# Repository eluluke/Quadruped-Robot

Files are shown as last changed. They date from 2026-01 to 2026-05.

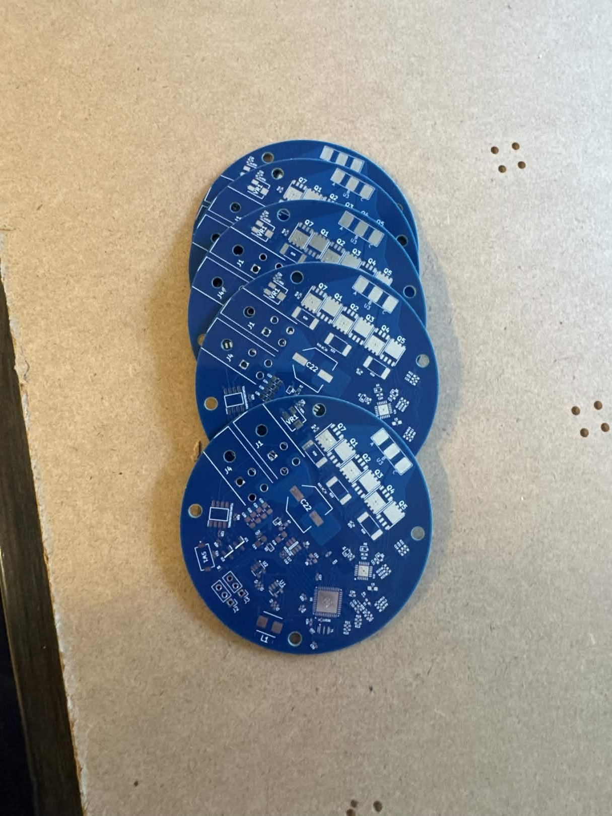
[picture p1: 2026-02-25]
Documentation/IMG_2081.jpg

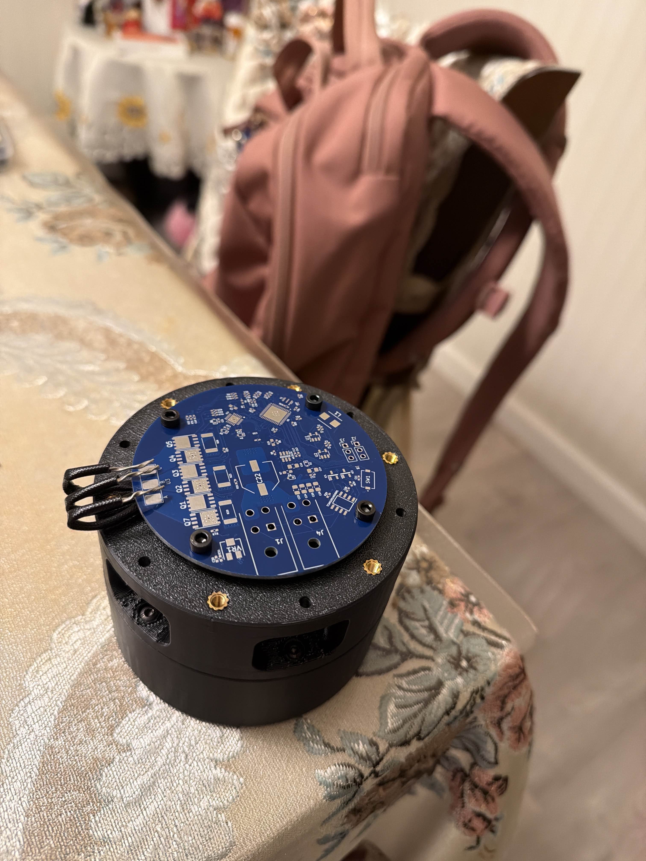
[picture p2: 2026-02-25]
Documentation/IMG_6219.jpg

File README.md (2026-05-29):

# Quadruped Robot

Open-source, 3D-printable, modular quadruped robot designed as a hardware platform for robotics education, controls development, kinematics, reinforcement learning, robotic vision, and future semi-commercial research applications.

This project focuses on building a practical legged robot platform using custom cycloidal actuators, off-the-shelf electronics, CAN-based motor communication, and open-source low-level motor control software. The goal is to create a robot that is mechanically capable, reproducible, and flexible enough for future work in locomotion, autonomous navigation, and robotics research.

## Project Overview

The quadruped is a 12-degree-of-freedom robotic platform with three actuated joints per leg. The mechanical design uses custom 3D-printed cycloidal actuators with a 17:1 gear ratio. These actuators were designed to make the robot modular, serviceable, and easier to manufacture using accessible tools such as 3D printers.

The CAD design is complete, and the actuator assemblies have been built. The current electronics setup uses off-the-shelf hardware for development and testing, while the repository also includes ongoing custom FOC driver board design files. Software development is focused on low-level actuator communication, calibration, inverse kinematics, single-leg testing, and full quadruped locomotion.

Full walking is still under development.

## Current Status

| Area | Status |
| --- | --- |
| CAD design | Complete |
| Actuator design | Complete |
| Actuator build | Complete |
| Electronics | Off-the-shelf electronics currently used for development |
| Custom FOC board | KiCad design files included / in development |
| Low-level motor communication | Based on Berkeley Humanoid Lite low-level code |
| Calibration scripts | In progress |
| Single-leg control | In progress |
| Full quadruped walking | In development |
| Vision/autonomy | Future work |

## Features

* 12-DOF quadruped layout
* Three actuators per leg
* Custom 17:1 cycloidal actuator design
* 3D-printable mechanical structure
* Modular leg and actuator design
* CAD files for the full robot body, legs, and accessories
* CAN-based actuator communication
* Low-level motor control using Berkeley Humanoid Lite/Recoil-style communication code
* Calibration scripts for actuator setup and configuration
* Forward and inverse kinematics tools
* Early locomotion and gait-control scripts
* Xbox controller testing scripts for manual actuator/robot control
* KiCad files for custom FOC driver board development
* BOM and purchasing documentation

## Repository Structure

```text
Quadruped-Robot/
├── 3D_Model/
│   ├── Accessory/
│   ├── Quadruped Body/
│   └── Quadruped Leg/
│
├── Control_Code/
│   ├── Calibration/
│   ├── Locomotion/
│   ├── lowlevel_actuator/
│   ├── quad_ik_can/
│   └── recoil/
│
├── Documentation/
│
├── KiCAD Files/
│   ├── 3D models/
│   ├── BHL_S1_Current/
│   ├── Footprints/
│   ├── Protoype1_Final_revision/
│   └── Symbols/
│
├── Motor_Firmware/
│
├── Purchasing/
│   ├── BOM/
│   └── RFF/
│
└── README.md
```

## Folder Descriptions

### `3D_Model/`

Contains the mechanical design files for the robot. This includes accessory parts, the quadruped body assembly, and leg assembly files.

Important areas include:

* `Accessory/` — printable accessory parts such as body covers and handles
* `Quadruped Body/` — full robot body assembly files
* `Quadruped Leg/` — leg assembly files

These files are used for manufacturing, assembly planning, and future mechanical revisions.

### `Control_Code/`

Contains the Python control software for actuator testing, calibration, kinematics, and early locomotion development.

#### `Control_Code/Calibration/`

Scripts used for setting up and validating individual actuators and motor controllers.

Examples include:

* `ping.py` — basic communication test
* `calibrate_electrical_offset.py` — motor/encoder electrical offset calibration
* `configure_parameter.py` — motor controller parameter configuration
* `read_configurations.py` — read back motor controller settings
* `move_actuator.py` — basic actuator motion test

#### `Control_Code/Locomotion/`

Main area for robot-level locomotion development.

Includes:

* Forward kinematics
* Inverse kinematics
* Leg configuration
* Gain configuration
* Gait scheduling
* Robot controller scripts
* Xbox controller configuration
* IMU reading utilities
* Single-leg and quadruped testing scripts

Notable files include:

* `quadruped_leg_fk.py`
* `quadruped_leg_ik.py`
* `leg_controller.py`
* `robot_controller.py`
* `gait_scheduler.py`
* `quadruped_main_slim.py`
* `quadruped_main_state.py`
* `single_leg_trot.py`
* `remote_single_leg_trot.py`
* `xbox_home_v5.py`
* `read_bno055_live.py`

#### `Control_Code/lowlevel_actuator/`

Contains lower-level actuator test scripts used to command one or more actuators directly.

Examples include:

* `actuator_move_position.py`
* `actuator_ramp_position.py`
* `actuator_ramp_rel_pos.py`
* `triple_actuator_homing.py`
* `triple_actuator_rel_pos.py`
* `xbox_position_control_test.py`
* `xbox_velocity_control_test.py`

These scripts are useful for validating actuator behavior before integrating the full robot.

#### `Control_Code/quad_ik_can/`

Contains an additional inverse-kinematics-over-CAN control workflow.

Includes:

* `can_interface.py`
* `config.py`
* `ik_solver.py`
* `main.py`
* `README.md`

This section appears to be focused on combining inverse kinematics commands with CAN communication.

#### `Control_Code/recoil/`

Contains the low-level Recoil-style communication code used to interface with the FOC motor drivers.

This project uses the Berkeley Humanoid Lite low-level code as the foundation for communicating with the FOC drivers.

Files include:

* `can.py`
* `core.py`
* `fixed16.py`
* `util.py`

## Mechanical Design

The robot is built around custom cycloidal actuators. Each actuator is designed to be compact, modular, and manufacturable with accessible tools. The use of a cycloidal gearbox provides a high reduction ratio while keeping the actuator package suitable for legged robotics.

The mechanical system was designed with the following goals:

* Keep the robot modular and easy to repair
* Make the actuator design reproducible
* Use 3D printing where practical
* Reduce complexity compared to fully custom machined systems
* Provide enough torque and structure for walking development
* Create a platform that can support future controls and autonomy work

## Electronics

The current robot uses off-the-shelf electronics for development and testing. This makes it easier to focus on actuator validation, CAN communication, calibration, and walking control before depending on fully custom hardware.

The repository also includes KiCad files for custom FOC driver board development. These files include PCB designs, schematics, footprints, symbols, 3D models, and previous design revisions.

### `KiCAD Files/`

This folder contains custom motor controller PCB design files and related KiCad resources.

Included resources:

* KiCad project files
* PCB layout files
* Schematic files
* Footprints
* Symbols
* 3D models
* Older board revisions
* Prototype revisions

This section is useful for future development of custom motor-control electronics.

### `Motor_Firmware/`

Contains motor firmware resources, including a modified Recoil motor controller firmware archive.

## Software

The control software is written primarily in Python and is organized around actuator bring-up, calibration, inverse kinematics, and locomotion development.

The current low-level communication approach is based on the Berkeley Humanoid Lite low-level code. This code is used to communicate with the FOC drivers and send actuator commands over CAN.

### Software Goals

* Establish reliable communication with each actuator
* Test individual motor and actuator behavior
* Validate actuator direction, encoder feedback, and control modes
* Calibrate electrical offsets and controller parameters
* Develop single-leg control
* Develop inverse kinematics for each leg
* Build toward coordinated full-body locomotion
* Eventually support higher-level walking, autonomy, and vision experiments

## Running and Testing

Example test scripts are available in the Berkeley Humanoid Lite low-level software and in this repository’s `Control_Code/` folder.

A typical development workflow is:

1. Set up the Python environment.
2. Connect the CAN interface and motor controller hardware.
3. Confirm communication with the actuator.
4. Run a basic ping or configuration read test.
5. Calibrate the actuator electrical offset.
6. Test basic actuator movement.
7. Test multiple actuators together.
8. Run inverse kinematics tests.
9. Test single-leg motion.
10. Move toward full quadruped locomotion.

Example scripts to start with:

```bash
python Control_Code/Calibration/ping.py
python Control_Code/Calibration/read_configurations.py
python Control_Code/Calibration/calibrate_electrical_offset.py
python Control_Code/Calibration/move_actuator.py
```

For low-level actuator tests:

```bash
python Control_Code/lowlevel_actuator/actuator_move_position.py
python Control_Code/lowlevel_actuator/actuator_ramp_position.py
python Control_Code/lowlevel_actuator/triple_actuator_homing.py
```

For locomotion and kinematics development:

```bash
python Control_Code/Locomotion/ik_terminal_test.py
python Control_Code/Locomotion/single_leg_trot.py
python Control_Code/Locomotion/quadruped_main_slim.py
python Control_Code/Locomotion/quadruped_main_state.py
```

Exact commands may need to be adjusted depending on the CAN interface, operating system, motor IDs, and hardware configuration.

## Development Notes

This project is still actively being developed. Many scripts are experimental and may need to be updated for a specific hardware setup.

Before running full robot tests, verify:

* CAN interface name and bitrate
* Motor controller IDs
* Encoder direction
* Motor phase order
* Joint limits
* Homing offsets
* Control gains
* Power supply current limit
* Emergency stop or disconnect method

## Safety Notes

This project involves motors, gear reductions, motor controllers, power electronics, and moving robotic limbs. Use caution when testing.

Recommended safety practices:

* Test actuators one at a time before full robot integration
* Keep the robot lifted or supported during early walking tests
* Use current limits during initial motor testing
* Keep hands, wires, and tools away from moving joints
* Have an emergency stop or quick power disconnect available
* Double-check wiring before applying power
* Verify motor direction before installing actuators into the full robot
* Confirm joint limits before running autonomous motion
* Avoid testing high-power motion near people or fragile objects
* Monitor motor and driver temperature during testing
* Do not leave powered actuators unattended

This robot is still under development, so all testing should be done carefully and incrementally.

## Documentation

The `Documentation/` folder contains project images and supporting documents. More build documentation, assembly instructions, wiring diagrams, CAD renders, and videos will be added as the project progresses.

## Purchasing and BOM

The `Purchasing/` folder contains bill of materials files, expense tracking, and request-for-funding documentation.

This includes:

* FOC drive board BOM
* Overall robot BOM
* Expense tracker
* Funding/request documentation

These files are useful for tracking cost, sourcing parts, and documenting project funding.

## Roadmap

### Completed

* Designed the full quadruped CAD model
* Designed custom cycloidal actuators
* Built the actuator assemblies
* Created 3D-printable body, leg, and accessory files
* Set up off-the-shelf electronics for development
* Added low-level actuator testing scripts
* Added calibration scripts
* Added forward and inverse kinematics code
* Added early locomotion and single-leg test scripts
* Added KiCad files for custom FOC driver board development

### In Progress

* Low-level actuator testing
* Motor communication and control validation
* Actuator calibration
* Leg-level control development
* Gait scheduling
* Single-leg trot testing
* Full quadruped walking development

### Future Work

* Full quadruped walking demo
* Improved gait generation
* Higher-level body control
* Autonomous navigation
* Robotic vision integration
* Custom electronics refinement
* Cleaner software setup instructions
* Assembly guide
* Wiring diagrams
* CAD renders and demo videos
* More complete documentation for calibration and testing

## Acknowledgments

This project uses the Berkeley Humanoid Lite low-level code as the foundation for communication with the FOC drivers.

The project is inspired by open-source robotics platforms and the goal of making advanced legged robotics more accessible for students, researchers, and builders.

## Project Status Disclaimer

This repository is still a work in progress. The CAD and actuator builds are complete, but full walking control is still under development. Some scripts are experimental and may require hardware-specific configuration before use.

## License

License information has not been finalized yet. Add the appropriate license before using this project for public distribution or commercial work.

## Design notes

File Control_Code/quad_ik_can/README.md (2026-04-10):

# Quad Leg IK — CAN Tester
**STM32 BESC · CANable · SocketCAN · Python 3**

Interactive inverse kinematics visualiser that sends computed joint angles
over CAN bus to three STM32 BESC motor controllers — one per joint.

---

## Quick Start

### 1. Install dependencies

```bash
pip3 install python-can
# tkinter is usually built-in; if not:
sudo apt-get install python3-tk
```

### 2. Bring up the CANable

Plug in your CANable USB adapter, then:

```bash
sudo bash scripts/setup_can.sh          # default: /dev/ttyACM0
# or if your device is on a different port:
sudo bash scripts/setup_can.sh /dev/ttyACM1
```

This creates the `can0` SocketCAN interface at 1 Mbit/s.

### 3. Run the app

```bash
python3 main.py
```

---

## Files

```
quad_ik_can/
├── config.py          ← ALL tunable parameters (edit this first)
├── ik_solver.py       ← Pure IK math (no hardware dependency)
├── can_interface.py   ← python-can wrapper for STM32 BESC
├── main.py            ← tkinter GUI application
└── scripts/
    └── setup_can.sh   ← CANable bringup script
```

---

## Configuration  (`config.py`)

### Link Lengths
```python
L1 = 100.0   # mm — upper arm (hip → knee)
L2 =  90.0   # mm — lower arm (knee → ankle)
L3 =  70.0   # mm — foot link (ankle → toe)
```
Edit these (or use the GUI panel) once you have your measurements.

### CAN IDs
```python
CAN_ID_HIP   = 0x01
CAN_ID_KNEE  = 0x02
CAN_ID_ANKLE = 0x03
```
Also editable live in the GUI without restarting.

### Joint Limits
```python
HIP_LIMIT_DEG   = (-90.0,  90.0)
KNEE_LIMIT_DEG  = (  0.0, 150.0)
ANKLE_LIMIT_DEG = (-90.0,  90.0)
```
Angles outside these ranges are clamped before transmission and shown
in red in the GUI.

### Angle Offsets
```python
HIP_OFFSET_DEG   = 0.0
KNEE_OFFSET_DEG  = 0.0
ANKLE_OFFSET_DEG = 0.0
```
Added to each IK angle before sending. Use to zero mechanical offsets.

---

## CAN Frame Format (STM32 BESC)

| Field | Value |
|---|---|
| Arbitration ID  | Joint CAN ID (0x01 / 0x02 / 0x03) |
| DLC | 4 bytes |
| Data | IEEE-754 float32, little-endian, degrees |

Example — hip at 30.0°:
```
ID: 0x001   DLC: 4   Data: 00 00 F0 41
```

---

## Simulation Mode

If `python-can` is not installed **or** the CAN interface is not available,
the app runs in **SIMULATION MODE** — all IK math runs normally, angles
are displayed and logged, but no frames are sent. The CAN log shows
`[SIM]` and the status indicator turns orange.

---

## Parallelogram Linkage Note

The IK solver treats the leg as a standard 3-DOF serial chain. For a true
parallelogram linkage the actuated joint angle equals the effective link
angle (transmission ratio = 1.0). If your linkage has a different ratio set:

```python
KNEE_TRANSMISSION_RATIO = 1.0   # in config.py
```

The knee angle sent over CAN is multiplied by this value.

---

## Troubleshooting

| Symptom | Fix |
|---|-----|
| `can0: No such device` | Run `setup_can.sh` first |
| `Permission denied /dev/ttyACM0` | `sudo usermod -aG dialout $USER` then re-login |
| Motors don't move | Check CAN IDs match firmware; verify bitrate |
| Wrong angle direction | Flip sign with offset: `HIP_OFFSET_DEG = 0` + negate in `can_interface.py` |
| GUI doesn't open | `sudo apt-get install python3-tk` |

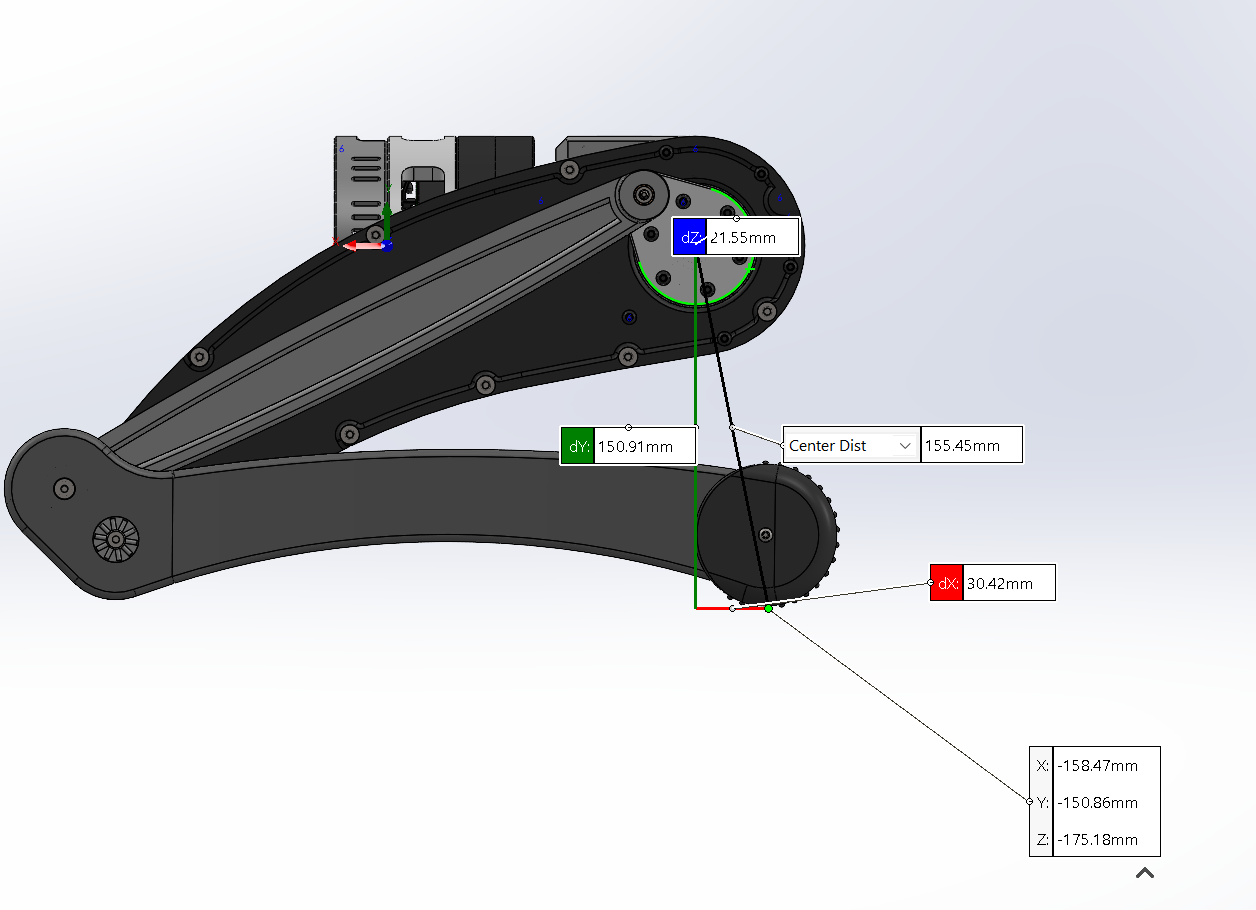
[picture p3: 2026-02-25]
Documentation/image.png

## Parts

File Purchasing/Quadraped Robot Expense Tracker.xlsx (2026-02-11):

Project
Expenses
Project | Start Date | End Date | Total: | $197.93
Quadraped Robot | 2025-11-15 | 2026-06-09
Member | Expense | Type | Amount | Notes
Elijah | DigiKey | Electrical | $8.76 | FOC Drive Board Components
Elijah | JLCPCB | PCB Board | $34.97 | FOC Drive Board
Elijah | Mouser | Electrical | $20.16 | FOC Drive Board Components
Elijah | DigiKey | Electrical | $126.04 | FOC Drive Board Components
Elijah | Amazon | Electrical | $8.00 | Molex connectors
MooMoo | Amazon | Gearbox |  | Cycloidal Gear Box Components
MooMoo | Amazon | Gearbox |  | Cycloidal Gear Box Components
MooMoo | Amazon | Gearbox |  | Cycloidal Gear Box Components
MooMoo | Amazon | Gearbox |  | Cycloidal Gear Box Components
Total |  |  | $197.93

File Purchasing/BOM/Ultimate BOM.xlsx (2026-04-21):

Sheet: Total Price
Item NO. | Item | Price | Quantity | Total | Item NO. | Item | Price | Total
1 | Actuator | $84.63 | 12 | $1015.58 | 1 | Actuator | $84.63 | $209.00 | In amazon cart
2 | Leg Assembly | $43.94 | 12 | $527.34 | 2 | Leg Assembly | $43.94 | $158.33 | In amazon cart
3 | FOC Drive Board | $38.51 | 12 | $462.17 | 3 | FOC Drive Board | $0.00 | $0.00
4 | Raspberry Pi 5 | $175.00 | 1 | $175.00 | 4 | Raspberry Pi 5 | $175.00 | $175.00 | https://www.canakit.com/raspberry-pi-5-8gb.html
5 | 3D Printer Filament | $15.00 | 4 | $60.00 | 5 | Motor Control Dev Board | $19.35 | $239.19 | https://www.digikey.com/short/43vvtr80
6 | Body Assembly | $89.98 | 1 | $89.98 | 6 | Body Assembly | $89.98 | $89.98 | In amazon cart
Total Project Cost: |  |  |  | $2330.07 | Additional Funding Needed: |  |  | $859.67
 |  |  |  |  |  | ^^^^^^^
 |  |  |  |  | This is the box that you should look at.

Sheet: Body Assembly
ITEM NO. | PART NUMBER | DESCRIPTION | Web Link for Purchasing | Cost per Time Purchased($) | Quantity Per Time Purchased (pcs & kg) | Part Unit Cost Per Purcahse($) | QTY. | Cost per Assembly | Units In Stock | Units Needed For Complete Quadruped | Extra Cost Needed For Complete Quadruped
1 | Printed Body Part | All printed body parts including center body, shoulder-chest, and hip supporting panels printed with PLA | https://a.co/d/0axj8nc5 | $26.98 | 2 | $10.00 | 2 | $19.99 | 0 | 2 | $39.98
2
3
4
5
6 | 600MM Length Carbon Fiber Tube | Carbon Fiber Rods | https://a.co/d/098f3vCr | $25.00 | 2 | $12.50 | 2 | $25.00 | 0 | 4 | $50.00
7
8
9
10
Total Cost Per Assembly($): |  |  |  |  |  |  |  | $44.99 | Extra Cost Needed For Complete Quadruped($): |  | $89.98

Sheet: Cycloidal Gearbox
ITEM NO. | PART NUMBER | DESCRIPTION | Web Link for Purchasing | Cost per Time Purchased($) | Quantity Per Time Purchased (pcs & kg) | Part Unit Cost Per Purcahse($) | QTY. | Cost per Assembly | Units In Stock | Units Needed For Complete Quadruped | Extra Cost Needed For Complete Quadruped
1 | Ring Gear | PLA Filament | https://a.co/d/0gjZemYR | $29.98 | 0.0301 | $0.45 | 1 | $0.45 | 1 | 12 | $4.96
2 | Opposite Ring Gear |  |  |  | 0.0301 | $0.45 | 1 | $0.45 | 1 | 12 | $4.96
3 | Cycloidal Gear |  |  |  | 0.0115 | $0.17 | 2 | $0.34 | 2 | 24 | $3.78 | 1.8468
4 | Input Shaft |  |  |  | 0.0036 | $0.05 | 1 | $0.05 | 1 | 12 | $0.59
5 | Spacer Washer |  |  |  | 0.0002 | $0.002 | 1 | $0.0023984 | 1 | 12 | $0.02
6 | Bearing Spacer Big |  |  |  | 0.0004 | $0.01 | 1 | $0.01 | 1 | 12 | $0.07
7 | "HM155kV Motor Mount V2" |  |  |  | 0.0422 | $0.63 | 1 | $0.63 | 1 | 12 | $6.96
8 | Encoder Magnent Mount |  |  |  | 0.0005 | $0.01 | 1 | $0.01 | 1 | 12 | $0.08
9 | Shaft Coupler for HM155KV |  |  |  | 0.0032 | $0.05 | 1 | $0.05 | 1 | 12 | $0.54
10 | FOC Board Spacer |  |  |  | 0.0001 | $0.002 | 4 | $0.01 | 4 | 48 | $0.09
11 | V3 Output Shaft Opposite |  |  |  | 0.0125 | $0.19 | 1 | $0.19 | 1 | 12 | $2.07
12 | V2 Output Shaft |  |  |  | 0.0195 | $0.29 | 1 | $0.29 | 1 | 12 | $3.22
13 | "50mm*65mm*7mm Ball Bearing" | Bearing For both Ring Gears | https://a.co/d/0iJVO1oG | $28.09 | 10 | $2.81 | 2 | $5.62 | 5 | 24 | $53.37
14 | "M3*0.5 BY 25mm Socket Head Screw" | Screw to secure two Ring Gears together | https://a.co/d/0gNaFcET | $8.39 | 50 | $0.17 | 6 | $1.01 | 20 | 72 | $8.73
15 | 15mm by 24mm by 5mm Ball Bearing | Beaing for Cycloidal Gear | https://a.co/d/02tsqvkJ | $9.59 | 10 | $0.96 | 1 | $0.96 | 4 | 12 | $7.67
16 | M3 by 8mm Button Head Cap Screw | Screw for both Motor Mount and Motor Coupler connection | https://a.co/d/02je179N | $5.99 | 50 | $0.12 | 6 | $0.72 | 0 | 72 | $8.63
17 | M4 by 8mm Button Head Cap Screw | Screw to secure the HM155kv onto Motor Mount | https://a.co/d/0fTSP7Vz | $7.99 | 50 | $0.16 | 4 | $0.64 | 22 | 48 | $4.15
18 | M3 by 2.4mm Hex Nut | Nut to secure the FOC Board | https://a.co/d/09MJXPxa | $5.49 | 200 | $0.03 | 8 | $0.22 | 25 | 48 | $0.63
19 | HM-6208 motor | Electric Motor | https://www.hobbywingdirect.com/products/xrotor-m-6208-motor-ul | $60.00 | 1 | $60.00 | 1 | $60.00 | 12 | 12 | $0.00
20 | 22mm*10mm*6mm Ball Bearing | Bearing to secure the Input Shaft | https://a.co/d/02soELBD | $8.29 | 8 | $1.04 | 1 | $1.04 | 6 | 12 | $6.22
21 | M2.5 by 25mm Socket Head Screw | Screw to secure and strengthen the Ouput Shaft | https://a.co/d/09MJXPxa | $9.79 | 50 | $0.20 | 6 | $1.17 | 15 | 72 | $11.16
22 | 8mm*10mm*12mm Sleeve Bearing | Bearing to be used at the contact of Cycloidal Gear and the Output Shaft | https://a.co/d/0ckISucZ | $7.19 | 8 | $0.90 | 6 | $5.39 | 24 | 72 | $43.14
23 | 25mm*37mm*7mm Bearing | Bearing to secure the Motor Coupler and the Input Shaft on the Output Shaft | https://a.co/d/0cG1vUeo | $13.19 | 10 | $1.32 | 1 | $1.32 | 9 | 12 | $3.96
24 | M3 by 5mm by 6mm Heat Insert | Heat Insert Nut for screw connection | https://a.co/d/04sPH867 | $9.19 | 100 | $0.09 | 30 | $2.76 | 18 | 360 | $31.43
25 | M2.5 by 4mm by 6mm Heat Insert | Heat Insert Nut for screw connection | https://a.co/d/0fmXszQq | $9.19 | 100 | $0.09 | 6 | $0.55 | 44 | 72 | $2.57
26 | Encoder Magnent | Used on Encoder Magnent Mount for Position Feedback | https://a.co/d/0dExNett | $15.10 | 20 | $0.76 | 1 | $0.76 | 15 | 12 | $0.00
Total Cost Per Assembly($): |  |  |  |  |  |  |  | $84.63 | Extra Cost Needed For Complete Quadruped($): |  | $209.00

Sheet: Leg Assembly
ITEM NO. | PART NUMBER | DESCRIPTION | Web Link for Purchasing | "Cost per Time Purchased($)" | "Quantity Per Time Purchased (pcs & kg)" | "Part Unit Cost Per Purcahse($)" | QTY. | "Cost per Assembly" | "Units In Stock (Non-repetitive)" | Units Needed For Complete Quadruped | Extra Cost Needed For Complete Quadruped
1 | "Quadruped Thigh outer" | 3D printed PLA | https://a.co/d/0gjZemYR | $26.98 | 0.1845 | $2.49 | 1 | $2.49 | 0 | 4 | $9.96
2 | "Quadruped Thigh inner" |  |  |  | 0.1735 | $2.34 | 1 | $2.34 | 0 | 4 | $9.36
3 | "Quadruped Thigh Linkage" |  |  |  | 0.0199 | $0.27 | 1 | $0.27 | 0 | 4 | $1.07 | 3.4164
4 | "Quadruped Leg linkage" |  |  |  | 0.0654 | $0.88 | 1 | $0.88 | 0 | 4 | $3.53
5 | "Quadruped Small Leg whole" |  |  |  | 0.1858 | $2.51 | 1 | $2.51 | 0 | 4 | $10.03
16 | "Actuator back cover for quadruped" |  |  |  | 0.0593 | $0.80 | 1 | $0.80 | 0 | 4 | $3.20
17 | "Quadruped Hip Bracket" |  |  |  | 0.122 | $1.65 | 1 | $1.65 | 0 | 4 | $6.58
18 | Actuator back cover |  |  |  | 0.0437 | $0.59 | 2 | $1.18 | 0 | 8 | $4.72
20 | Quadruped Foot | 3D Printed TPU | https://a.co/d/0dviCzEQ | $8.99 | 0.0388 | $1.39 | 1 | $1.39 | 0 | 4 | $5.58
19 | "50*65*7MM BALL BEARING" | Bearing for the Actuator Cover for Quadruped | https://a.co/d/0iJVO1oG | $28.09 | 10 | $2.81 | 3 | $8.43 | 0 | 12 | $33.71
21 | M3*6*5 insert | Heat Insert Nut for screw connection | https://a.co/d/02RLsYz4 | $9.19 | 100 | $0.09 | 12 | $1.10 | 0 | 48 | $4.42
22 | M4*0.7*25mm Shoulder Screw | For Small Leg Linkage Connection | https://a.co/d/09Na5hOE | $2.48 | 5 | $0.50 | 2 | $0.99 | 9 | 8 | $0.00
23 | M3*0.5*2.5mm Hex Nut | For Foot Connection | https://a.co/d/09gTfF0x | $5.99 | 200 | $0.03 | 24 | $0.72 | 0 | 96 | $2.88
6 | M4*0.7*55mm Countersunk Screw | For Thigh Connection | https://a.co/d/0ifwolvi | $6.99 | 10 | $0.70 | 7 | $4.89 | 0 | 28 | $19.57
7 | "M4*4*6mm heat insert" | Heat Insert Nut For Screw Connection | https://a.co/d/09anQYCh | $7.29 | 50 | $0.15 | 7 | $1.02 | 19 | 28 | $1.31
8 | M3*12mm Button Head Cap Screw | Screw For Most Gear Box-Motor Housing Connection | https://a.co/d/005UyY34 | $8.19 | 100 | $0.08 | 24 | $1.97 | 0 | 96 | $7.86
9 | 5*8*6mm sleeve | Sleeve Bearing Support for Leg Linkage Pin connection | https://a.co/d/05sPvYRi | $12.79 | 40 | $0.32 | 7 | $2.24 | 0 | 28 | $8.96
10 | "6*19*2 thrust bearing with washer" | Thrust Bearing Support for Linkage mechanism | https://a.co/d/0bDdVhIm | $8.29 | 10 | $0.83 | 5 | $4.14 | 8 | 20 | $9.95
11 | M4*0.7*45mm Shoulder Screw | For Thigh-Small Leg Connection | https://a.co/d/08z1tbBh | $8.69 | 8 | $1.09 | 1 | $1.09 | 0 | 4 | $4.34
12 | M4*0.7*3.2mm Hex Nut | Hex Nut For Most Shoulder Bolt Connection | https://a.co/d/03sRPgfF | $6.29 | 100 | $0.06 | 3 | $0.19 | 40 | 12 | $0.00
14 | 5*8*10mm sleeve | Sleeve Bearing Support for Linkage Pin connection | https://a.co/d/05cPeEqb | $13.29 | 40 | $0.33 | 3 | $1.00 | 10 | 12 | $0.66
15 | M3*16mm Socket Head Cap Screw | Screw For Most Actuattor-Leg Components Connection | https://a.co/d/09MrIxQw | $7.39 | 50 | $0.15 | 18 | $2.66 | 0 | 72 | $10.64
Total Cost Per Assembly($): |  |  |  |  |  |  |  | $43.94 | Extra Cost Needed For Complete Quadruped($): |  | $158.33

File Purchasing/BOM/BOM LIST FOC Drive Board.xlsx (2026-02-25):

Id | Designator | Footprint | Quantity | Designation | Total Bought | Total For 12 Boards | Percentage | 5 Boards | Store Bought | Bought?
1 | C27,C35,C18,C34,C4,C12,C31,C33,C28,C32,C30,C3,C17,C13,C36 | C_0402_1005Metric_Pad0.74x0.62mm_HandSolder | 15 | 0.1uF | 180 | 180 | 100% | 75 | Mouser | X
2 | C23,C25,C24,C26 | C_0805_2012Metric_Pad1.18x1.45mm_HandSolder | 4 | 10uF/35V | 48 | 48 | 100% | 20 | Mouser | X
3 | R21,R24,R19,R22,R25,R18 | R_0402_1005Metric_Pad0.72x0.64mm_HandSolder | 6 | 22 | 72 | 72 | 100% | 30 | Mouser | X
4 | R38 | R_0402_1005Metric_Pad0.72x0.64mm_HandSolder | 1 | 1M | 12 | 12 | 100% | 5 | Mouser | X
5 | C11 | C_0402_1005Metric_Pad0.74x0.62mm_HandSolder | 1 | 1000pF | 12 | 12 | 100% | 5 | Mouser | X
6 | R20,R23,R26 | R_2512_6332Metric_Pad1.40x3.35mm_HandSolder | 3 | 3mOhm | 36 | 36 | 100% | 15 | Mouser | X
7 | C22 | 470uF_10mm_Cap | 1 | 470uF | 12 | 12 | 100% | 5 | Mouser | X
8 | R12,R9,R15 | R_0402_1005Metric_Pad0.72x0.64mm_HandSolder | 3 | 1.5K | 36 | 36 | 100% | 15 | Mouser | X
9 | D5,D4,D6 | D_SOD-523 | 3 | 1N4148WT | 36 | 36 | 100% | 15 | Mouser | X
10 | J2,J3 | PinHeader_1x03_P2.54mm_Vertical | 2 | Conn_01x03_Pin | 24 | 24 | 100% | 10 | Mouser | X
11 | L1 | INDPM5452X300N_Inductor | 1 | 6.8uH | 12 | 12 | 100% | 5 | Mouser | X
12 | ME3116 | SOT95P270X145-6N_ME3116 | 1 | ME3116 | 10 | 12 | 83.33333333% | 5 | MooMoo bought it | X
13 | U1 | SOT-23-5 | 1 | ME6211C30M5 | 10 | 12 | 83.33333333% | 5 | MooMoo bought it | X
14 | IC2,IC1 | SOT96P237X111-3N_DIODE | 2 | NUP2105LT1G | 24 | 24 | 100% | 10 | Mouser | X
15 | R29,R30 | R_0402_1005Metric_Pad0.72x0.64mm_HandSolder | 2 | 0 | 24 | 24 | 100% | 10 | Mouser | X
16 | Q5,Q2,Q1,Q7,Q3,Q4 | CSD19502Q5B_MOSFET | 6 | CSD19502Q5B | 30 | 72 | 41.66666667% | 30 | Mouser | X
17 | R35 | R_01005_0402Metric_Pad0.57x0.30mm_HandSolder | 1 | 0 | 12 | 12 | 100% | 5 | Mouser | X
18 | D1 | LED_0402_1005Metric_Pad0.77x0.64mm_HandSolder | 1 | LED GREEN | 12 | 12 | 100% | 5 | Mouser | X
19 | IC4 | QFN50P400X400X90-25N-D_Gatedriver1 | 1 | FD6288Q | 10 | 12 | 83.33333333% | 5 | MooMoo bought it | X
20 | R13,R14,R10 | R_0402_1005Metric_Pad0.72x0.64mm_HandSolder | 3 | 22K | 36 | 36 | 100% | 15 | Mouser | X
21 | R8 | R_0402_1005Metric_Pad0.72x0.64mm_HandSolder | 1 | 1K | 12 | 12 | 100% | 5 | Mouser | X
22 | D2,D3 | D_SOD-523 | 2 | STPS1L40M | 24 | 24 | 100% | 10 | Mouser | X
23 | R31 | R_0402_1005Metric_Pad0.72x0.64mm_HandSolder | 1 | 169K | 12 | 12 | 100% | 5 | Mouser | X
24 | R37,R4 | R_01005_0402Metric_Pad0.57x0.30mm_HandSolder | 2 | 10K | 24 | 24 | 100% | 10 | Mouser | X
25 | J1,J4 | Terminator | 2 | 39-30-1042 | 5 | 24 | 20.83333333% | 10 | Mouser | X
26 | C21,C19,C20 | C_0402_1005Metric_Pad0.74x0.62mm_HandSolder | 3 | 1uF/25V | 36 | 36 | 100% | 15 | Mouser | X
27 | R16,R11,R17 | R_0402_1005Metric_Pad0.72x0.64mm_HandSolder | 3 | 2.2K | 36 | 36 | 100% | 15 | Mouser | X
28 | C16,C14 | C_0805_2012Metric_Pad1.18x1.45mm_HandSolder | 2 | 10uF | 24 | 24 | 100% | 10 | Mouser | X
29 | U2 | SOT-23-5 | 1 | SPX3819M5-L-5-0 | 10 | 12 | 83.33333333% | 5 | MooMoo bought it | X
30 | R5 | R_01005_0402Metric_Pad0.57x0.30mm_HandSolder | 1 | 510K | 12 | 12 | 100% | 5 | DigiKey | X
31 | R34,R33 | R_0402_1005Metric_Pad0.72x0.64mm_HandSolder | 2 | 10K | 24 | 24 | 100% | 10 | Mouser | X
32 | SW1 | SW_PTS636_CNK | 1 | PTS636 SM50J SMTR LFS | 12 | 12 | 100% | 5 | DigiKey | X
33 | U5 | QFN50P700X700X60-49N_STM32 | 1 | STM32G431CBU6 | 6 | 12 | 50% | 5 | Mouser | X
34 | R36 | R_0402_1005Metric_Pad0.72x0.64mm_HandSolder | 1 | 4.7K | 12 | 12 | 100% | 5 | Mouser | X
35 | TCAN1051HGVDR1 | SOIC127P600X175-8N_CAN | 1 | ~ | 10 | 12 | 83.33333333% | 5 | MooMoo bought it | X
36 | VR1 | Trimmer_Potentiometer | 1 | 10k | 10 | 12 | 83.33333333% | 5 | MooMoo bought it | X
37 | C5 | C_0603_1608Metric_Pad1.08x0.95mm_HandSolder | 1 | 10uF/35V | 12 | 12 | 100% | 5 | Mouser | X
38 | C2,C1 | C_0402_1005Metric_Pad0.74x0.62mm_HandSolder | 2 | 10uF | 24 | 24 | 100% | 10 | Mouser | X
39 | R32 | R_0402_1005Metric_Pad0.72x0.64mm_HandSolder | 1 | 18K | 12 | 12 | 100% | 5 | Mouser | X
40 | C15 | C_0603_1608Metric_Pad1.08x0.95mm_HandSolder | 1 | 100pF | 12 | 12 | 100% | 5 | Mouser | X
41 | U3 | Soldering Pad for BLDC motor | 1 | Solder Pad | 12 | 12 | 100% | 5 | Mouser | X
42 | Y1 | CSTNE8M00G55Z000R0_Resonator | 1 | 8MHz | 12 | 12 | 100% | 5 | MooMoo bought it | X
43 | R7 | R_0603_1608Metric_Pad0.98x0.95mm_HandSolder | 1 | 1M | 12 | 12 | 100% | 5 | Mouser | X
44 | R6 | R_0402_1005Metric_Pad0.72x0.64mm_HandSolder | 1 | 14K | 12 | 12 | 100% | 5 | Mouser | X
45 | AS5600 | AS5600 | 1 | ~ | 10 | 12 | 83.33333333% | 5 | MooMoo bought it | X
 |  |  |  |  | Total Percentage Bought |  | 93.24%

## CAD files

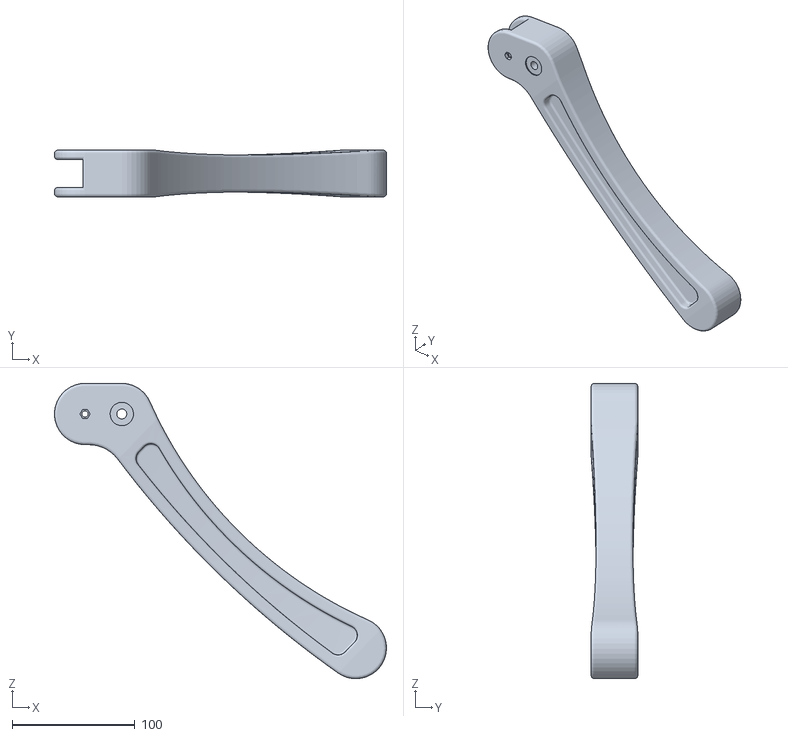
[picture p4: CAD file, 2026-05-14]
3D_Model/Quadruped Leg/Leg_stl/Left legs/Quadruped Small Leg whole.STL
270.8 x 38.0 x 240.9

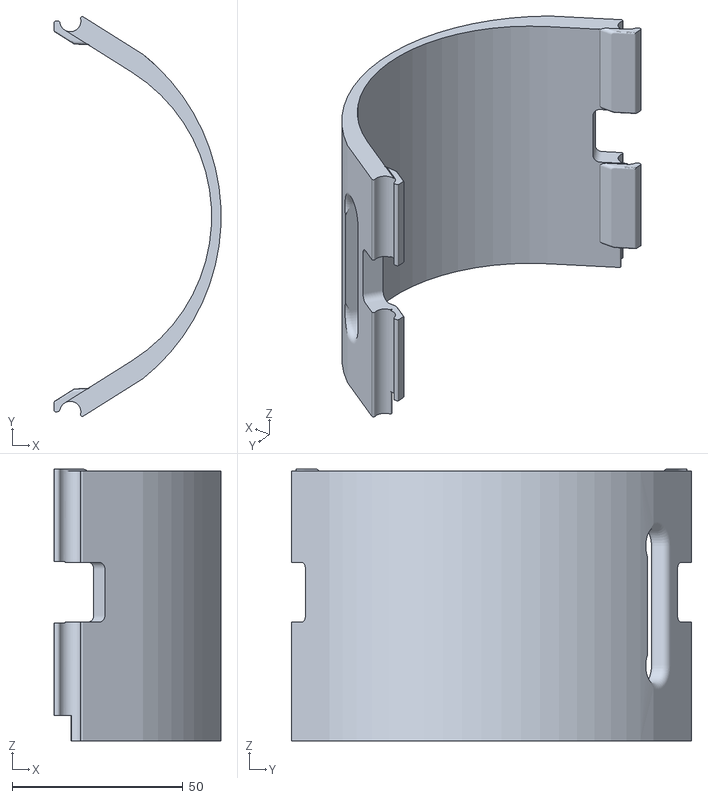
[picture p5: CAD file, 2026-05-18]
3D_Model/Accessory/Center Body Flip Cover.STL
48.8 x 117.0 x 79.5

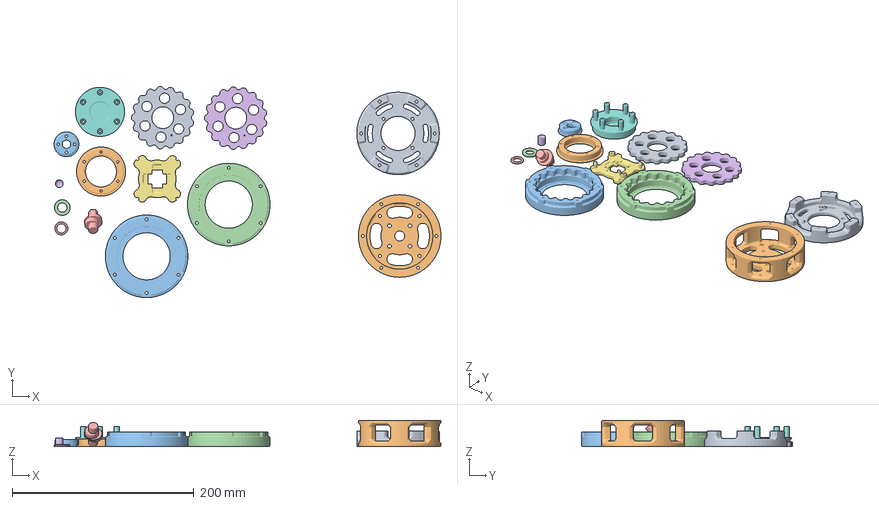
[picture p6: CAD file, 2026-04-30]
3D_Model/Actuators/Cycloidal_Actuator_Final_Rev/3mf/Cycloidal_Actuator_Final_Revision.3mf
426.4 x 232.7 x 28.8 mm
Actuator back cover for BG431.STL
HM155kV MOTOR MOUNT V2.STL
V3 opposite ring gear.STL
V3 ring gear.STL
V2 INPUT SHAFT.STL
V2 Cycloidal gear.STL x 2
AS5600 Encoder Mount.STL
V2 OUTPUT SHAFT.STL
V3 Output shaft opp.STL
Shaft coupler for EA60.STL
Bearing spacer Big.STL
SPACER WASHER.STL
Encoder magnent mount.STL

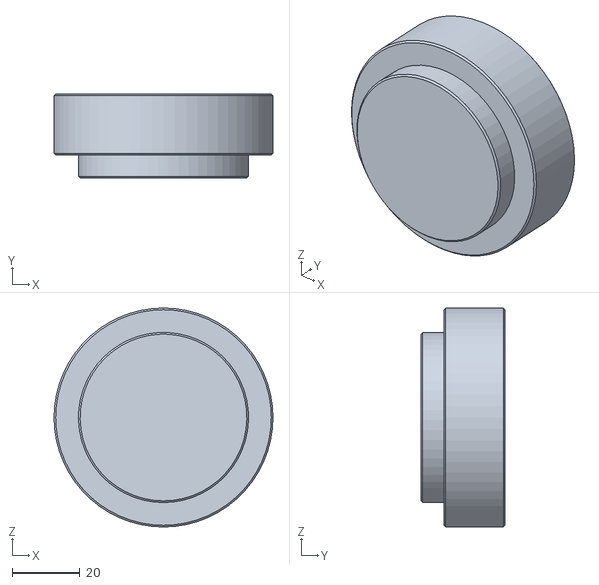
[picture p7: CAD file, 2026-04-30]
3D_Model/Actuators/Cycloidal_Actuator_Final_Rev/STL/Bearing Pressing for 50 by 65mm.STL
64.5 x 24.8 x 64.5

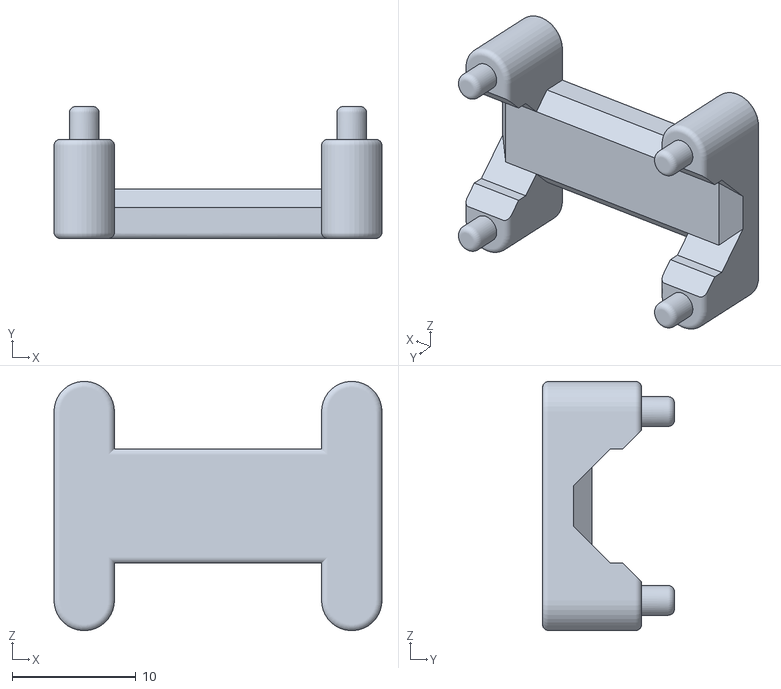
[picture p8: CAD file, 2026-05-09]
3D_Model/Electronics/Electronic Hardware STL/IMU Mount.STL
26.5 x 10.7 x 20.1

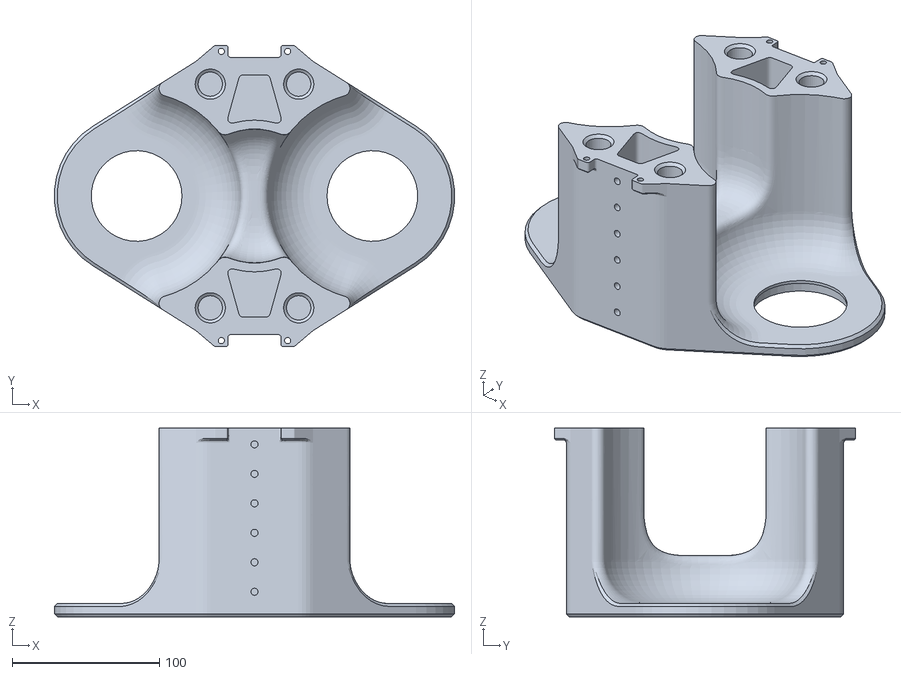
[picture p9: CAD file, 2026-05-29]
3D_Model/Quadruped Body/Body_stl/Hip Dual Support Face Panel.STL
271.5 x 204.3 x 128.0

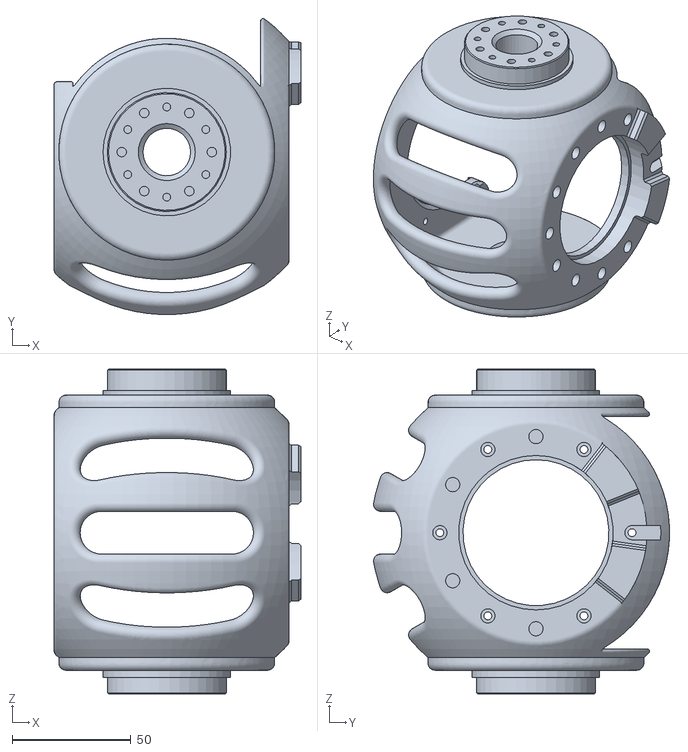
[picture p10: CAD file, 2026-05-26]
3D_Model/Quadruped Body/Hip_bracket_stl/Quadruped Hip Bracket Left Rear.STL
104.1 x 124.8 x 137.0

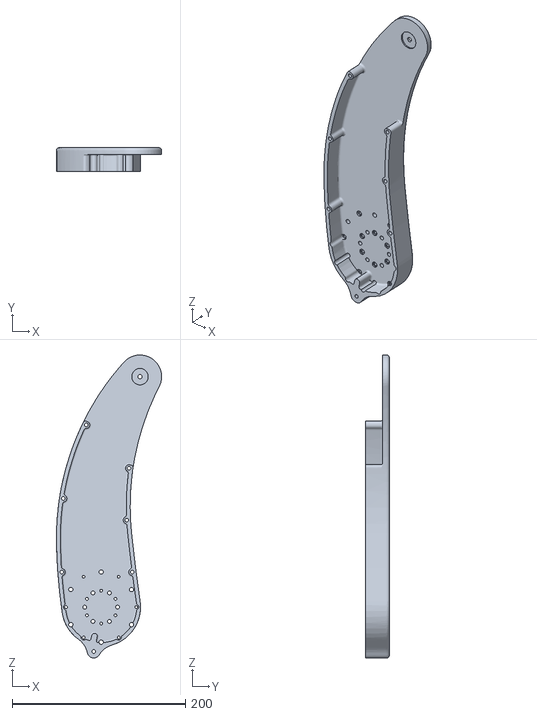
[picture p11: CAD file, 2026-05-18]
3D_Model/Quadruped Leg/Leg_stl/Left legs/Quadruped Thigh inner.STL
121.6 x 27.5 x 350.0

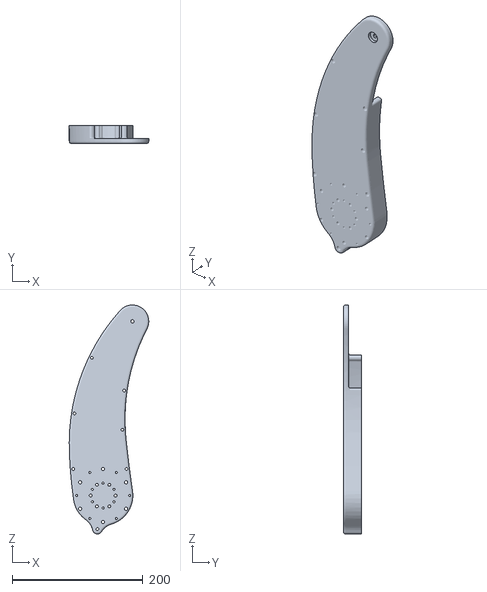
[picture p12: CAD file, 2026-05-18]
3D_Model/Quadruped Leg/Leg_stl/Right leg/Quadruped Thigh Mirrored Inner Right.STL
121.6 x 27.5 x 350.0

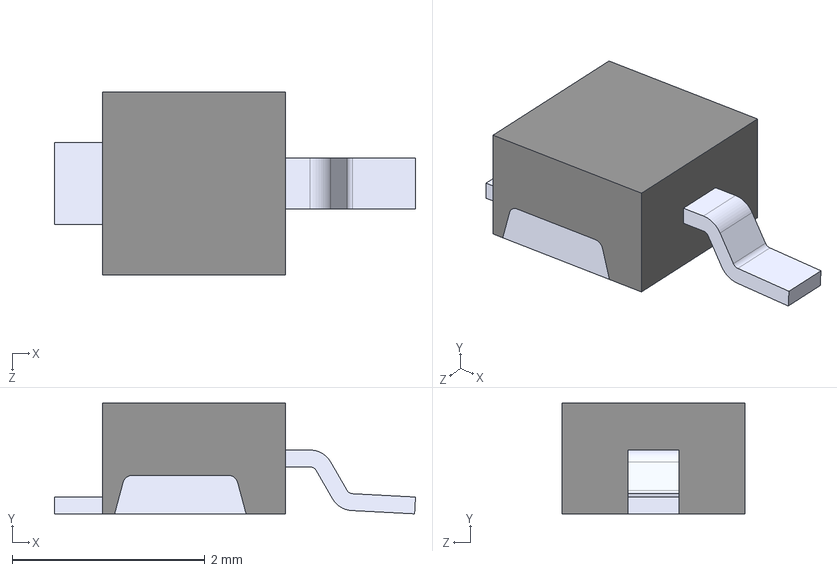
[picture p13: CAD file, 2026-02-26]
KiCAD Files/3D models/STPS1L40M.step
3.75 x 1.15 x 1.90 mm

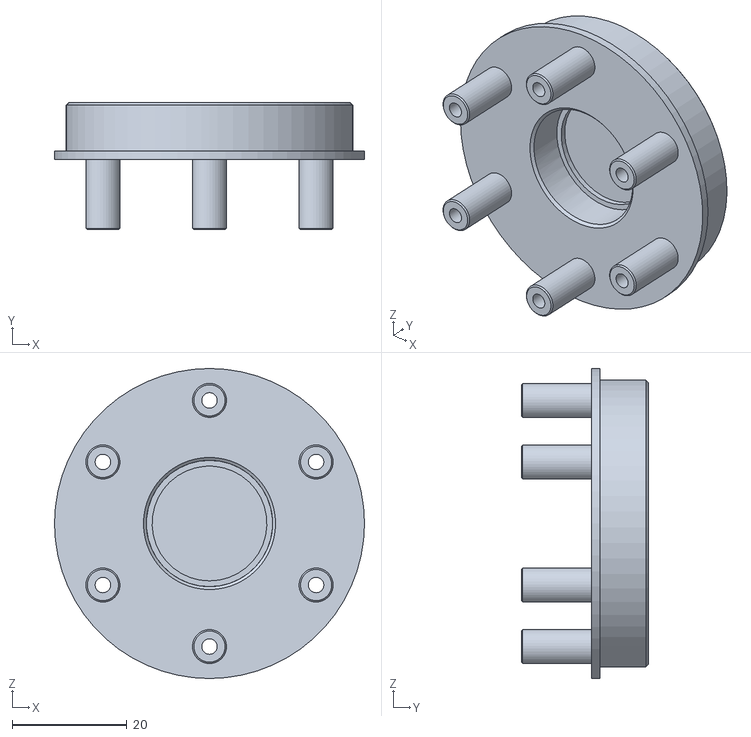
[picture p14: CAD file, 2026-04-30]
3D_Model/Actuators/Cycloidal_Actuator_Final_Rev/STL/V2 OUTPUT SHAFT.STL
54.2 x 22.2 x 54.2

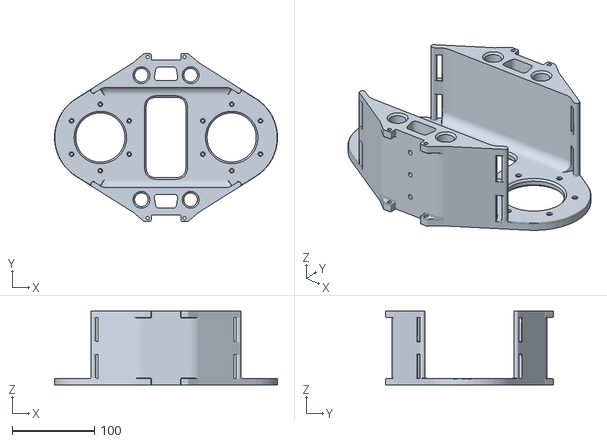
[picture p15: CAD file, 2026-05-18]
3D_Model/Quadruped Body/Body_stl/Center Body Mirrored.STL
271.7 x 204.3 x 90.0

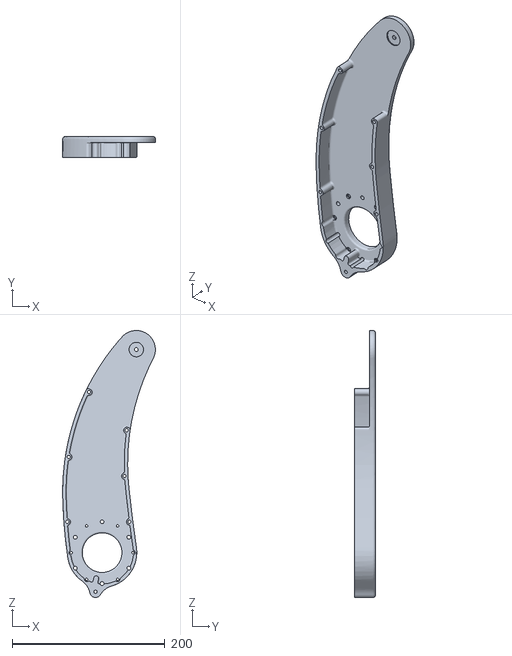
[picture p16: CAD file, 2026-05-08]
3D_Model/Quadruped Leg/Leg_stl/Right leg/Quadruped Thigh Mirrored Outer Right.STL
121.6 x 27.5 x 350.0

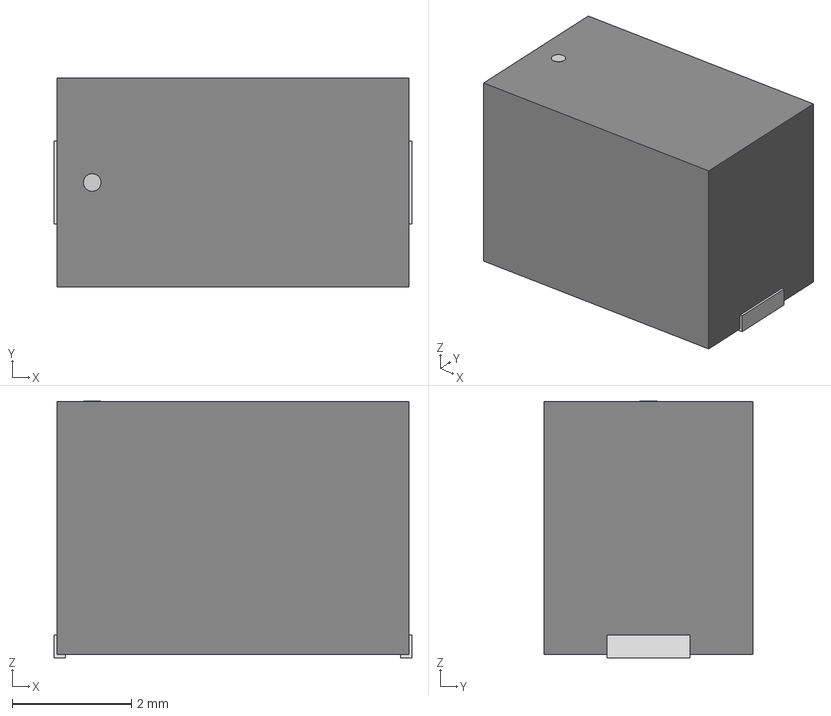
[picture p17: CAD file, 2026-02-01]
KiCAD Files/3D models/SW_PTS636_CNK.step
5.99 x 3.51 x 4.29 mm

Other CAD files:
3D_Model/Quadruped Leg/Leg_stl/Right leg/Quadruped Small Leg whole.STL
3D_Model/Accessory/Center Body Flip Cover Mirrored.STL
3D_Model/Quadruped Body/Hip_bracket_stl/Quadruped Hip Bracket Right Front.STL
3D_Model/Accessory/Quadruped Robot Handle.STL
3D_Model/Actuators/Cycloidal_Actuator_Final_Rev/STL/AS5600 Encoder Mount.STL
3D_Model/Actuators/Cycloidal_Actuator_Final_Rev/STL/Actuator back cover for BG431.STL
3D_Model/Actuators/Cycloidal_Actuator_Final_Rev/STL/Bearing Pressing for 10 by 22mm.STL
3D_Model/Actuators/Cycloidal_Actuator_Final_Rev/STL/Bearing spacer Big.STL
3D_Model/Actuators/Cycloidal_Actuator_Final_Rev/STL/Encoder magnent mount.STL
3D_Model/Actuators/Cycloidal_Actuator_Final_Rev/STL/HM155kV MOTOR MOUNT V2.STL
3D_Model/Actuators/Cycloidal_Actuator_Final_Rev/STL/SPACER WASHER.STL
3D_Model/Actuators/Cycloidal_Actuator_Final_Rev/STL/Shaft coupler for EA60.STL
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

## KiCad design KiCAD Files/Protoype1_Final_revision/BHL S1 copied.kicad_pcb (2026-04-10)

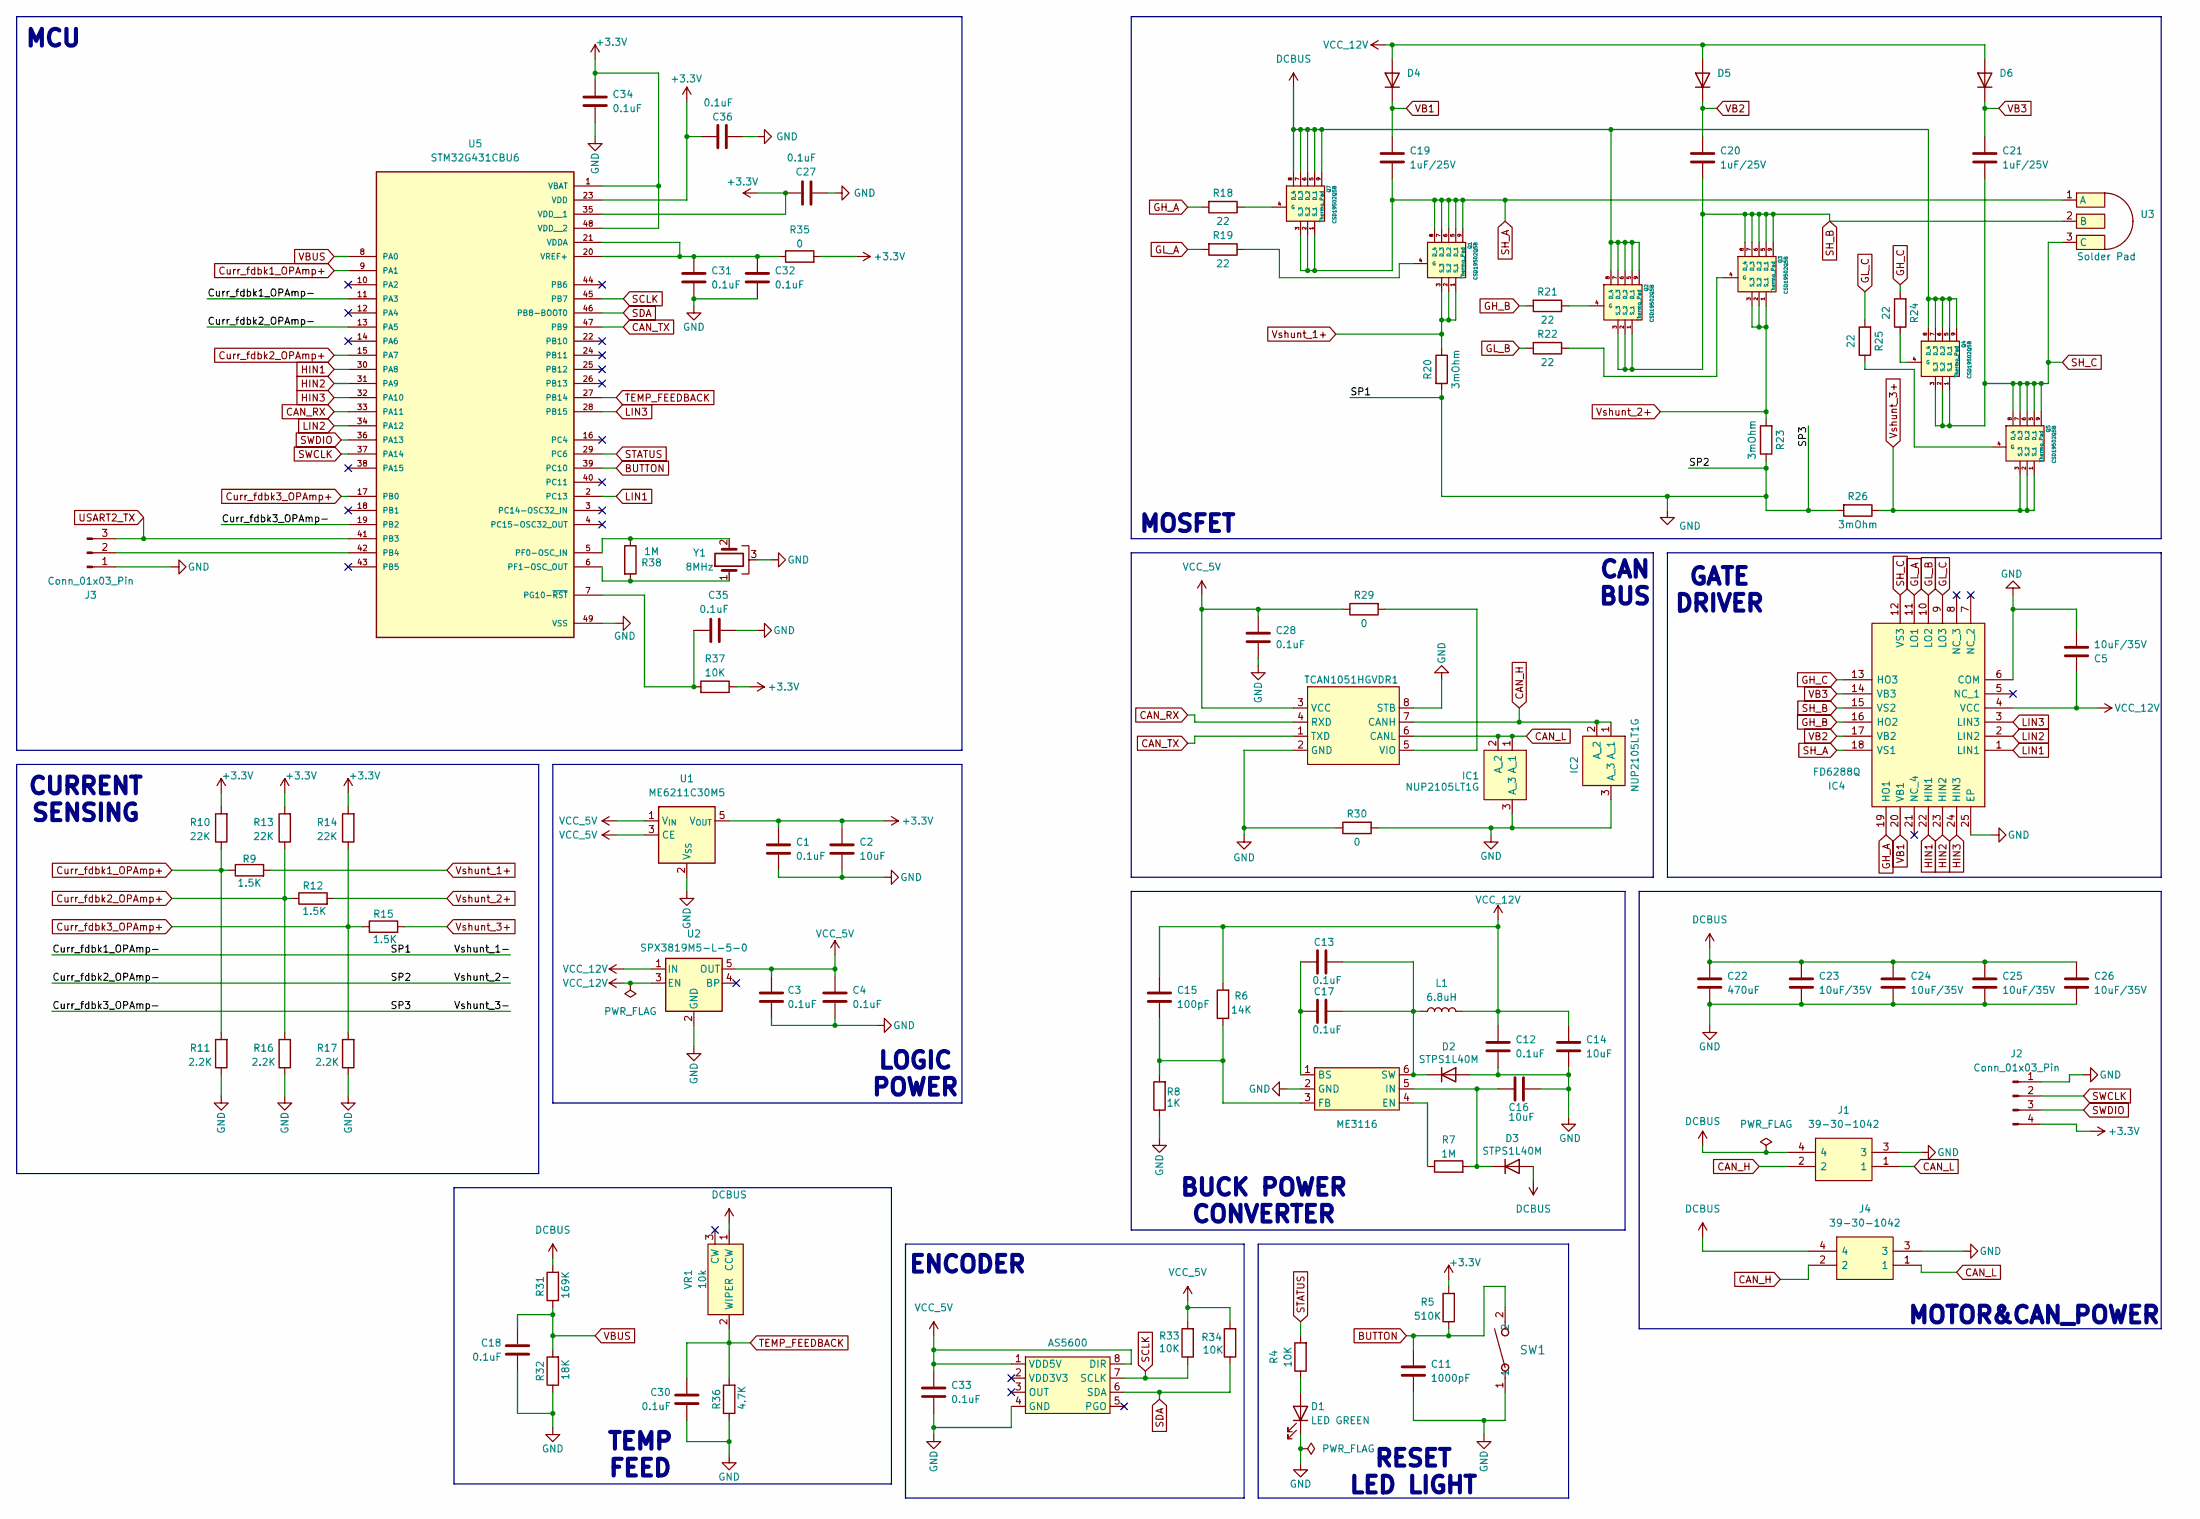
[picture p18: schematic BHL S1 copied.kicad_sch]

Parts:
AS5600: AS5600
C1, C3, C4, C12, C13, C17, C18, C27, C28, C30, C31, C32, C33, C34, C35, C36: 0.1uF; C_0402_1005Metric_Pad0.74x0.62mm_HandSolder
C2: 10uF; C_0402_1005Metric_Pad0.74x0.62mm_HandSolder
C5: 10uF/35V; C_0603_1608Metric_Pad1.08x0.95mm_HandSolder
C11: 1000pF; C_0402_1005Metric_Pad0.74x0.62mm_HandSolder
C14, C16: 10uF; C_0805_2012Metric_Pad1.18x1.45mm_HandSolder
C15: 100pF; C_0603_1608Metric_Pad1.08x0.95mm_HandSolder
C19, C20, C21: 1uF/25V; C_0402_1005Metric_Pad0.74x0.62mm_HandSolder
C22: 470uF; 470uF_10mm_Cap
C23, C24, C25, C26: 10uF/35V; C_0805_2012Metric_Pad1.18x1.45mm_HandSolder
D1: LED GREEN; LED_0402_1005Metric_Pad0.77x0.64mm_HandSolder
D2, D3: STPS1L40M; DIO_STPS1L40M
D4, D5, D6: 1N4148WT; D_SOD-523
IC1, IC2: NUP2105LT1G; SOT96P237X111-3N_DIODE; Mouser Part Number 863-NUP2105LT1G
IC4: FD6288Q; QFN50P400X400X90-25N-D_Gatedriver1; Manufacturer_Part_Number FD6288Q
J1, J4: 39-30-1042; Terminator; Mouser Part Number 538-39-30-1042
J2: Conn_01x03_Pin; PinHeader_1x04_P2.54mm_Vertical
J3: Conn_01x03_Pin; PinHeader_1x03_P2.54mm_Vertical
L1: 6.8uH; INDPM5452X300N_Inductor
ME3116: SOT95P270X145-6N_ME3116
Q1, Q2, Q3, Q4, Q5, Q7: CSD19502Q5B; CSD19502Q5B_MOSFET; Mouser Part Number 595-CSD19502Q5B
R4, R37: 10K; R_01005_0402Metric_Pad0.57x0.30mm_HandSolder
R5: 510K; R_01005_0402Metric_Pad0.57x0.30mm_HandSolder
R6: 14K; R_0402_1005Metric_Pad0.72x0.64mm_HandSolder
R7: 1M; R_0603_1608Metric_Pad0.98x0.95mm_HandSolder
R8: 1K; R_0402_1005Metric_Pad0.72x0.64mm_HandSolder
R9, R12, R15: 1.5K; R_0402_1005Metric_Pad0.72x0.64mm_HandSolder
R10, R13, R14: 22K; R_0402_1005Metric_Pad0.72x0.64mm_HandSolder
R11, R16, R17: 2.2K; R_0402_1005Metric_Pad0.72x0.64mm_HandSolder
R18, R19, R21, R22, R24, R25: 22; R_0402_1005Metric_Pad0.72x0.64mm_HandSolder
R20, R23, R26: 3mOhm; R_2512_6332Metric_Pad1.40x3.35mm_HandSolder
R29, R30: 0; R_0402_1005Metric_Pad0.72x0.64mm_HandSolder
R31: 169K; R_0402_1005Metric_Pad0.72x0.64mm_HandSolder
R32: 18K; R_0402_1005Metric_Pad0.72x0.64mm_HandSolder
R33, R34: 10K; R_0402_1005Metric_Pad0.72x0.64mm_HandSolder
R35: 0; R_01005_0402Metric_Pad0.57x0.30mm_HandSolder
R36: 4.7K; R_0402_1005Metric_Pad0.72x0.64mm_HandSolder
R38: 1M; R_0402_1005Metric_Pad0.72x0.64mm_HandSolder
SW1: PTS636 SM50J SMTR LFS; SW_PTS636_CNK
TCAN1051HGVDR1: SOIC127P600X175-8N_CAN
U1: ME6211C30M5; SOT-23-5
U2: SPX3819M5-L-5-0; SOT-23-5
U3: Solder Pad; Soldering Pad for BLDC motor
U5: STM32G431CBU6; QFN50P700X700X60-49N_STM32; PARTREV 6
VR1: 10k; Trimmer_Potentiometer; Mouser Part Number 652-3314J-1-103G
Y1: 8MHz; CSTNE8M00G55Z000R0_Resonator

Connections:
+3.3V: C1.1, C2.1, C27.1, C34.1, C36.1, J2.4, R5.2, R10.2, R13.2, R14.2, R35.2, R37.1, U1.5 (V_{OUT}), U5.1 (VBAT), U5.23 (VDD), U5.35 (VDD__1), U5.48 (VDD__2)
BUTTON: C11.1, R5.1, SW1.2, U5.39 (PC10)
CAN_H: IC2.1 (A), IC2.2 (A), J1.2, J4.2, TCAN1051HGVDR1.7 (CANH)
CAN_L: IC1.1 (A), IC1.2 (A), J1.1, J4.1, TCAN1051HGVDR1.6 (CANL)
CAN_RX: TCAN1051HGVDR1.4 (RXD), U5.33 (PA11)
CAN_TX: TCAN1051HGVDR1.1 (TXD), U5.47 (PB9)
Curr_fdbk1_OPAmp+: R9.1, R10.1, R11.2, U5.9 (PA1)
Curr_fdbk2_OPAmp+: R12.1, R13.1, R16.2, U5.15 (PA7)
Curr_fdbk3_OPAmp+: R14.1, R15.1, R17.2, U5.17 (PB0)
DCBUS: C22.1, C23.1, C24.1, C25.1, C26.1, D3.2 (A), J1.4, J4.4, Q2.5 (D_1), Q2.6 (D_2), Q2.7 (D_3), Q2.8 (D_4), Q2.9 (Thermo_Pad), Q4.5 (D_1), Q4.6 (D_2), Q4.7 (D_3), Q4.8 (D_4), Q4.9 (Thermo_Pad), Q7.5 (D_1), Q7.6 (D_2), Q7.7 (D_3), Q7.8 (D_4), Q7.9 (Thermo_Pad), R31.2, VR1.1 (CCW)
GH_A: IC4.19 (HO1), R18.2
GH_B: IC4.16 (HO2), R21.2
GH_C: IC4.13 (HO3), R24.2
GL_A: IC4.11 (LO1), R19.2
GL_B: IC4.10 (LO2), R22.2
GL_C: IC4.9 (LO3), R25.2
GND: AS5600.4 (GND), C1.2, C2.2, C3.2, C4.2, C5.2, C11.2, C12.2, C14.2, C16.1, C18.2, C22.2, C23.2, C24.2, C25.2, C26.2, C27.2, C28.2, C30.2, C31.2, C32.2, C33.2, C34.2, C35.1, C36.2, D1.1 (K), D2.2 (A), IC1.3 (A), IC2.3 (A), IC4.6 (COM), IC4.25 (EP), J1.3, J2.1, J3.1, J4.3, ME3116.2 (GND), R8.1, R11.1, R16.1, R17.1, R20.2, R23.1, R26.2, R30.1, R30.2, R32.1, R36.1, SW1.1, TCAN1051HGVDR1.2 (GND), TCAN1051HGVDR1.8 (STB), U1.2 (V_{SS}), U2.2 (GND), U5.11 (PA3), U5.13 (PA5), U5.19 (PB2), U5.49 (VSS), Y1.3
HIN1: IC4.22 (HIN1), U5.30 (PA8)
HIN2: IC4.23 (HIN2), U5.31 (PA9)
HIN3: IC4.24 (HIN3), U5.32 (PA10)
LIN1: IC4.1 (LIN1), U5.2 (PC13)
LIN2: IC4.2 (LIN2), U5.34 (PA12)
LIN3: IC4.3 (LIN3), U5.28 (PB15)
unnamed: D1.2 (A), R4.1
unnamed: C13.2, C17.2, D2.1 (K), L1.1, ME3116.6 (SW)
unnamed: C16.2, D3.1 (K), ME3116.5 (IN), R7.2
unnamed: J3.2, U5.42 (PB4)
unnamed: C13.1, C17.1, ME3116.1 (BS)
unnamed: ME3116.4 (EN), R7.1
unnamed: C15.2, ME3116.3 (FB), R6.1, R8.2
unnamed: Q1.4 (G), R19.1
unnamed: Q2.4 (G), R21.1
unnamed: Q3.4 (G), R22.1
unnamed: Q4.4 (G), R24.1
unnamed: Q5.4 (G), R25.1
unnamed: Q7.4 (G), R18.1
unnamed: R29.2, TCAN1051HGVDR1.5 (VIO)
unnamed: R38.1, U5.5 (PF0-OSC_IN), Y1.2
unnamed: R38.2, U5.6 (PF1-OSC_OUT), Y1.1
unnamed: C35.2, R37.2, U5.7 (PG10-~RST)
unnamed: C31.1, C32.1, R35.1, U5.20 (VREF+), U5.21 (VDDA)
SCLK: AS5600.7 (SCLK), R33.1, U5.45 (PB7)
SDA: AS5600.6 (SDA), R34.1, U5.46 (PB8-BOOT0)
SH_A: C19.2, IC4.18 (VS1), Q1.5 (D_1), Q1.6 (D_2), Q1.7 (D_3), Q1.8 (D_4), Q1.9 (Thermo_Pad), Q7.1 (S_1), Q7.2 (S_2), Q7.3 (S_3), U3.1 (A)
SH_B: C20.2, IC4.15 (VS2), Q2.1 (S_1), Q2.2 (S_2), Q2.3 (S_3), Q3.5 (D_1), Q3.6 (D_2), Q3.7 (D_3), Q3.8 (D_4), Q3.9 (Thermo_Pad), U3.2 (B)
SH_C: C21.2, IC4.12 (VS3), Q4.1 (S_1), Q4.2 (S_2), Q4.3 (S_3), Q5.5 (D_1), Q5.6 (D_2), Q5.7 (D_3), Q5.8 (D_4), Q5.9 (Thermo_Pad), U3.3 (C)
STATUS: R4.2, U5.29 (PC6)
SWCLK: J2.2, U5.37 (PA14)
SWDIO: J2.3, U5.36 (PA13)
TEMP_FEEDBACK: C30.1, R36.2, U5.27 (PB14), VR1.2 (WIPER)
USART2_TX: J3.3, U5.41 (PB3)
VB1: C19.1, D4.1 (K), IC4.20 (VB1)
VB2: C20.1, D5.1 (K), IC4.17 (VB2)
VB3: C21.1, D6.1 (K), IC4.14 (VB3)
VBUS: C18.1, R31.1, R32.2, U5.8 (PA0)
VCC_5V: AS5600.1 (VDD5V), AS5600.8 (DIR), C3.1, C4.1, C28.1, C33.1, R29.1, R33.2, R34.2, TCAN1051HGVDR1.3 (VCC), U1.1 (V_{IN}), U1.3 (CE), U2.5 (OUT)
VCC_12V: C5.1, C12.1, C14.1, C15.1, D4.2 (A), D5.2 (A), D6.2 (A), IC4.4 (VCC), L1.2, R6.2, U2.1 (IN), U2.3 (EN)
Vshunt_1+: Q1.1 (S_1), Q1.2 (S_2), Q1.3 (S_3), R9.2, R20.1
Vshunt_2+: Q3.1 (S_1), Q3.2 (S_2), Q3.3 (S_3), R12.2, R23.2
Vshunt_3+: Q5.1 (S_1), Q5.2 (S_2), Q5.3 (S_3), R15.2, R26.1

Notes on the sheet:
ENCODER
RESET LED LIGHT
MOSFET
TEMP FEED
MCU
BUCK POWER CONVERTER
LOGIC POWER
CURRENT SENSING
GATE DRIVER
MOTOR&CAN_POWER
CAN BUS

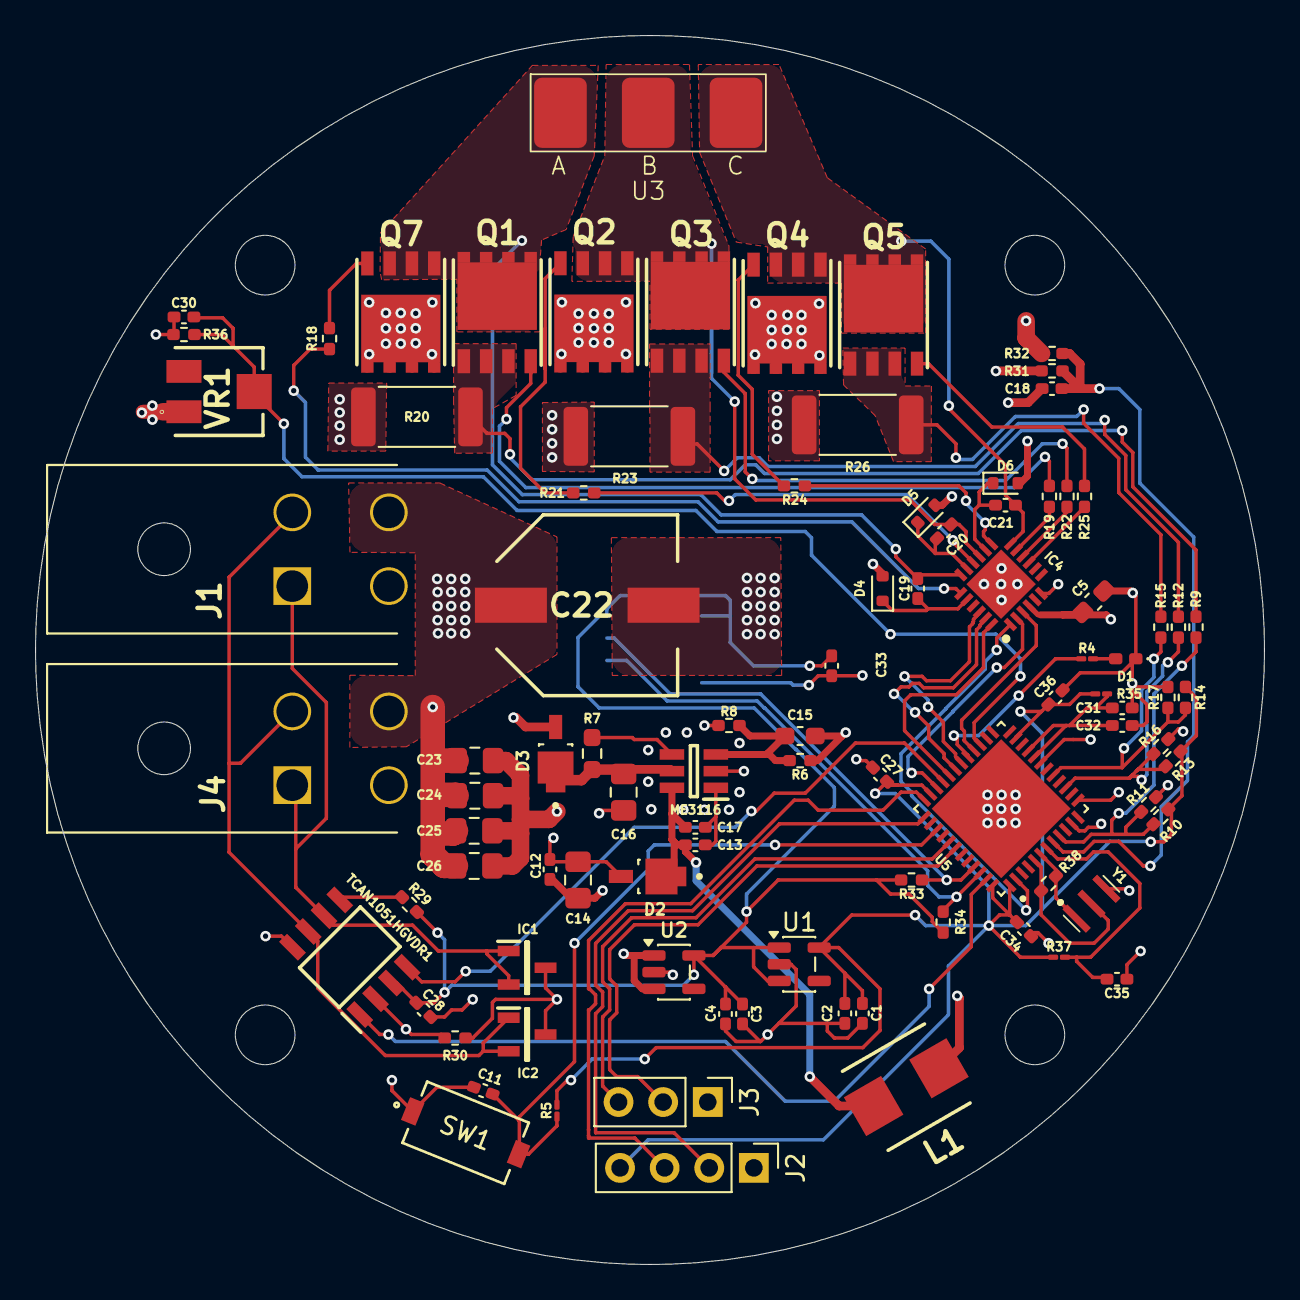
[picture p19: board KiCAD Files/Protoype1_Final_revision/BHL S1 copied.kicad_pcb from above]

Board: 4 copper layers, 70.0 x 70.0 mm, 93 parts (1 on the bottom side), 60 nets.

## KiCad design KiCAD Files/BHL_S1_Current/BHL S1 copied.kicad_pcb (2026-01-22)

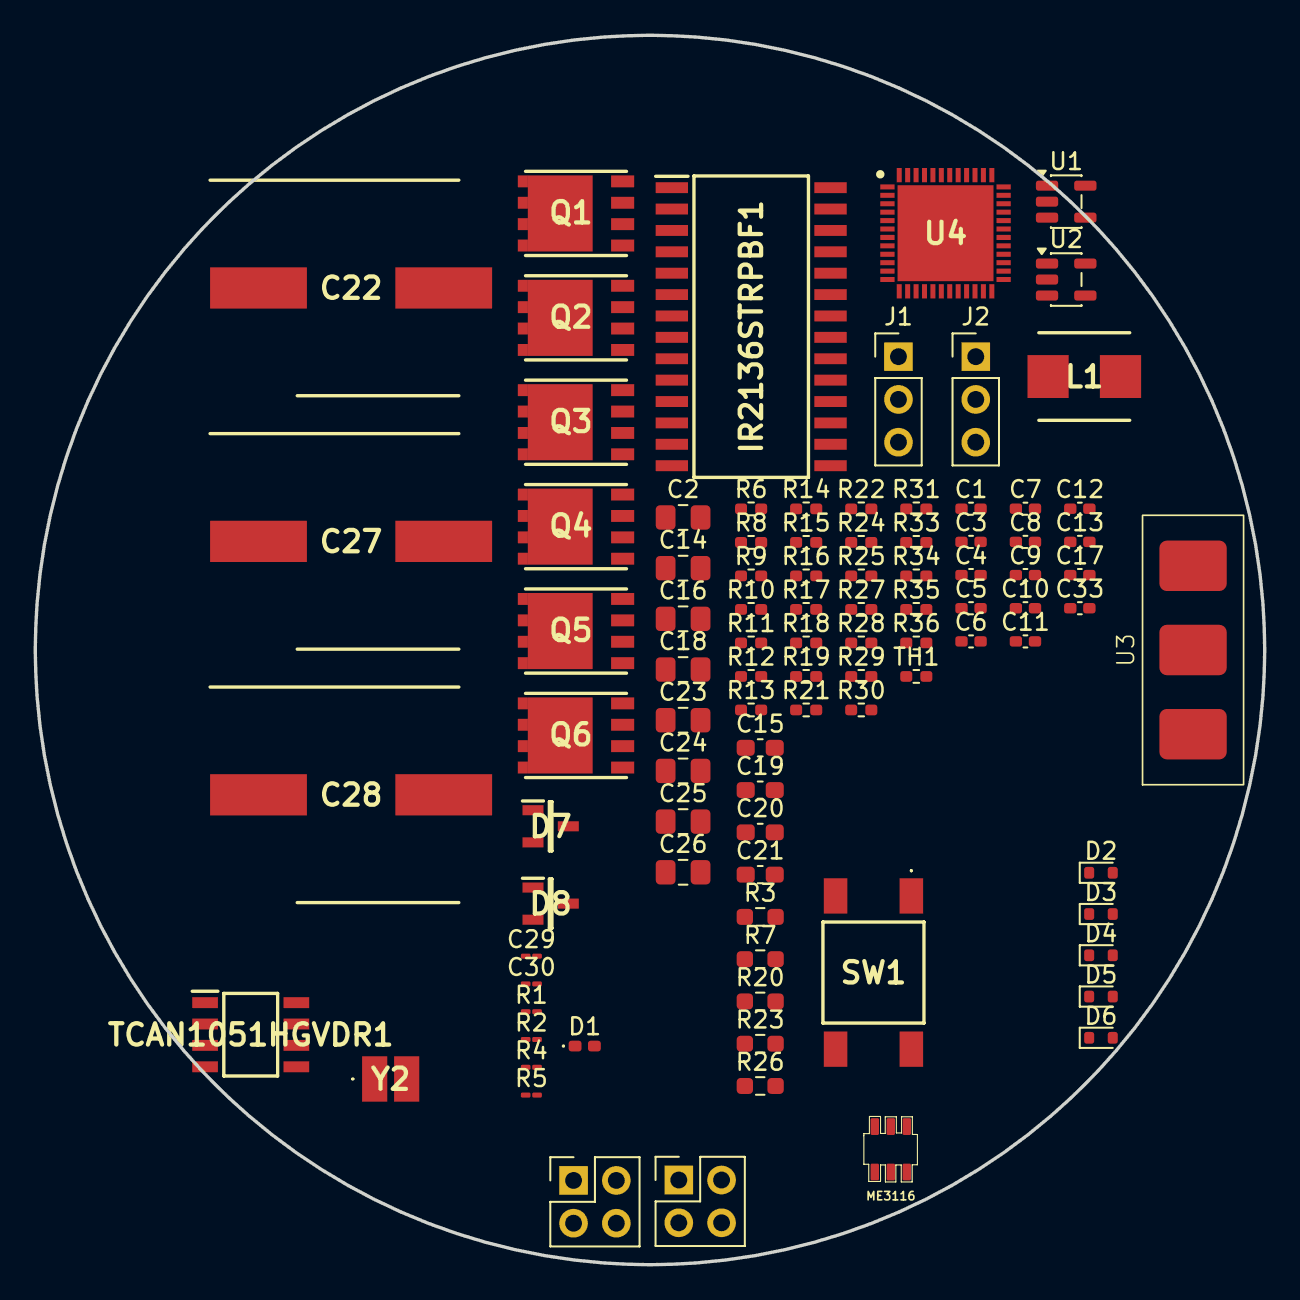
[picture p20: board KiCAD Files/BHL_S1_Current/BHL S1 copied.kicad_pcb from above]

Board: 2 copper layers, 73.0 x 73.0 mm, 96 parts (1 on the bottom side), 62 nets, no tracks yet.

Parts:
AS5600: AS5600
C1, C3, C4, C5, C6, C7, C8, C9, C10, C12, C13, C17, C33: 0.1uF; C_0402_1005Metric_Pad0.74x0.62mm_HandSolder
C2, C14, C16: 10uF; C_0805_2012Metric_Pad1.18x1.45mm_HandSolder
C11: 1000pF; C_0402_1005Metric_Pad0.74x0.62mm_HandSolder
C15: 100pF; C_0603_1608Metric_Pad1.08x0.95mm_HandSolder
C18, C23, C24, C25, C26: 10uF/35V; C_0805_2012Metric_Pad1.18x1.45mm_HandSolder
C19, C20, C21: 1uF/25V; C_0603_1608Metric_Pad1.08x0.95mm_HandSolder
C22, C27, C28: 470uF; CAPAE1280X1400N_Electrolytic Capacitor
C29, C30: 0.1uF; C_01005_0402Metric_Pad0.57x0.30mm_HandSolder
D1: LED GREEN; LED_0402_1005Metric_Pad0.77x0.64mm_HandSolder
D2, D3: STPS1L40M; D_SOD-523
D4, D5, D6: 1N4148WT; D_SOD-523
D7, D8: NUP2105; SOT96P237X111-3N_DIODE
Header2X2H1, Header2X2H2: PinHeader_2x02_P2.54mm_Vertical
IR2136STRPBF1: 3PHASE_GATE_DRIVER
J1, J2: Conn_01x03_Pin; PinHeader_1x03_P2.54mm_Vertical
L1: 6.8uH; INDPM5452X300N_Inductor
ME3116: ME3116AM6G_Regulator
Q1, Q2, Q3, Q4, Q5, Q6: CSD19502Q5B; CSD19502Q5B_MOSFET
R1: 0; R_01005_0402Metric_Pad0.57x0.30mm_HandSolder
R2: 10K; R_01005_0402Metric_Pad0.57x0.30mm_HandSolder
R3, R7: 1M; R_0603_1608Metric_Pad0.98x0.95mm_HandSolder
R4, R5: 510; R_01005_0402Metric_Pad0.57x0.30mm_HandSolder
R6: 14K; R_0402_1005Metric_Pad0.72x0.64mm_HandSolder
R8: 1K; R_0402_1005Metric_Pad0.72x0.64mm_HandSolder
R9, R12, R15: 1.5K; R_0402_1005Metric_Pad0.72x0.64mm_HandSolder
R10, R13, R14: 22K; R_0402_1005Metric_Pad0.72x0.64mm_HandSolder
R11, R16, R17: 2.2K; R_0402_1005Metric_Pad0.72x0.64mm_HandSolder
R18, R19, R21, R22, R24, R25: 22; R_0402_1005Metric_Pad0.72x0.64mm_HandSolder
R20, R23, R26: 3mOhm; R_0603_1608Metric_Pad0.98x0.95mm_HandSolder
R27, R28, R29, R30: 0; R_0402_1005Metric_Pad0.72x0.64mm_HandSolder
R31: 169K; R_0402_1005Metric_Pad0.72x0.64mm_HandSolder
R33, R34: 10K; R_0402_1005Metric_Pad0.72x0.64mm_HandSolder
R35: 18K; R_0402_1005Metric_Pad0.72x0.64mm_HandSolder
R36: 4.7K; R_0402_1005Metric_Pad0.72x0.64mm_HandSolder
SW1: SW_Push; Push Button 6x6mm
TCAN1051HGVDR1: SOIC127P600X175-8N_CAN
TH1: 10K; R_0402_1005Metric_Pad0.72x0.64mm_HandSolder
U1: ME6211C30M5; SOT-23-5
U2: SPX3819M5-L-5-0; SOT-23-5
U3: Solder Pad; Soldering Pad for BLDC motor
U4: STM32G431CBUx; STM32G431CBU6_MCU
Y2: 8MHz; ABM8AAIG8000MHzV2RT3_Crystal

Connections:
+3.3V: AS5600.1 (VDD5V), AS5600.8 (DIR), C1.1, C2.1, C3.1, C4.1, C5.1, C6.1, C9.1, C28.1, C33.1, R1.2, R2.1, R5.2, R10.2, R13.2, R14.2, R29.1, R33.2, R34.2, TCAN1051HGVDR1.3 (VCC), TH1.1, U1.1 (V_{IN}), U1.3 (CE), U1.5 (V_{OUT}), U2.5 (OUT), U4.1 (VBAT), U4.23 (VDD), U4.35 (VDD), U4.48 (VDD)
BEMF3: U4.16 (PC4), U4.24 (PB11)
BUTTON: C11.1, R5.1, SW1.1, U4.39 (PC10)
CAN_GND: D7.2 (A), D8.2 (A), R30.2, TCAN1051HGVDR1.8 (STB)
CAN_H: D8.1 (K), Header2X2H1.3, Header2X2H2.3, TCAN1051HGVDR1.7 (CANH)
CAN_L: D7.1 (K), Header2X2H1.4, Header2X2H2.4, TCAN1051HGVDR1.6 (CANL)
CAN_RX: TCAN1051HGVDR1.4 (RXD), U4.33 (PA11)
CAN_TX: TCAN1051HGVDR1.1 (TXD), U4.47 (PB9)
Curr_fdbk1_OPAmp+: R9.1, R10.1, R11.2, U4.9 (PA1)
Curr_fdbk1_OPAmp-: C22.2, C23.2, C24.2, C25.2, C26.2, C27.2, Header2X2H1.2, Header2X2H2.2, R20.2, R23.2, R26.2, R27.1, U4.11 (PA3), U4.13 (PA5), U4.19 (PB2)
Curr_fdbk2_OPAmp+: R12.1, R13.1, R16.2, U4.15 (PA7)
Curr_fdbk3_OPAmp+: R14.1, R15.1, R17.2, U4.17 (PB0)
DCBUS: C22.1, C23.1, C24.1, C25.1, C26.1, C27.1, D3.2 (A), Header2X2H1.1, Header2X2H2.1, Q2.1 (D), Q4.1 (D), Q6.1 (D), R31.1
GH_A: IR2136STRPBF1.19 (H01), R18.2
GH_B: IR2136STRPBF1.16 (HO2), R21.2
GH_C: IR2136STRPBF1.13 (HO3), R24.2
GL_A: IR2136STRPBF1.11 (L01), R19.2
GL_B: IR2136STRPBF1.10 (L02), R22.2
GL_C: IR2136STRPBF1.9 (L03), R25.2
GND: AS5600.4 (GND), C1.2, C2.2, C3.2, C4.2, C5.2, C6.2, C7.2, C8.2, C9.2, C10.1, C11.2, C12.2, C14.2, C16.1, C18.2, C28.2, C29.2, C30.2, C33.2, D1.1 (K), D2.2 (A), IR2136STRPBF1.6 (COM), IR2136STRPBF1.25 (EP), J1.2, J2.2, ME3116.2 (GND), R8.1, R11.1, R16.1, R17.1, R27.2, R28.1, R30.1, R35.2, R36.2, SW1.2, TCAN1051HGVDR1.2 (GND), U1.2 (V_{SS}), U2.2 (GND), U4.49 (VSS)
unnamed: D1.2 (A), R4.1
unnamed: C13.2, C17.2, D2.1 (K), L1.1, ME3116.4 (SW)
unnamed: C16.2, D3.1 (K), ME3116.5 (IN), R7.2
unnamed: J1.1, U4.42 (PB4)
unnamed: C13.1, C17.1, ME3116.1 (BS)
unnamed: ME3116.6 (EN), R7.1
unnamed: C15.2, ME3116.3 (FB), R6.1, R8.2
unnamed: Q1.2 (G), R19.1
unnamed: Q2.2 (G), R21.1
unnamed: Q3.2 (G), R22.1
unnamed: Q4.2 (G), R24.1
unnamed: Q5.2 (G), R25.1
unnamed: Q6.2 (G), R18.1
unnamed: R3.2, U4.5 (PF0), Y2.1
unnamed: R3.1, U4.6 (PF1), Y2.2
unnamed: C10.2, R2.2, U4.7 (PG10)
unnamed: C7.1, C8.1, R1.1, U4.20 (VREF+), U4.21 (VDDA)
SCLK: AS5600.7 (SCLK), R33.1, U4.46 (PB8)
SDA: AS5600.6 (SDA), R34.1, U4.45 (PB7)
SH_A: C19.2, IR2136STRPBF1.18 (VS1), Q1.1 (D), Q6.3 (S), U3.1 (A)
SH_B: C20.2, IR2136STRPBF1.15 (VS2), Q2.3 (S), Q3.1 (D), U3.2 (B)
SH_C: C21.2, IR2136STRPBF1.12 (VS3), Q4.3 (S), Q5.1 (D), U3.3 (C)
STATUS: R4.2, U4.29 (PC6)
SWCLK: J2.1, U4.37 (PA14)
SWDIO: J2.3, U4.36 (PA13)
TEMP_FEEDBACK: C30.1, R36.1, TH1.2, U4.27 (PB14)
TIM1_CH1: IR2136STRPBF1.22 (HN1), U4.30 (PA8)
TIM1_CH1N: IR2136STRPBF1.1 (LIN1), U4.2 (PC13)
TIM1_CH2: IR2136STRPBF1.23 (HN2), U4.31 (PA9)
TIM1_CH2N: IR2136STRPBF1.2 (LIN2), U4.34 (PA12)
TIM1_CH3: IR2136STRPBF1.24 (HN3), U4.32 (PA10)
TIM1_CH3N: IR2136STRPBF1.3 (LIN3), U4.28 (PB15)
USART2_TX: J1.3, U4.41 (PB3)
VB1: C19.1, D4.1 (K), IR2136STRPBF1.20 (VB1)
VB2: C20.1, D5.1 (K), IR2136STRPBF1.17 (VB2)
VB3: C21.1, D6.1 (K), IR2136STRPBF1.14 (VB3)
VBUS: C29.1, R31.2, R35.1, U4.8 (PA0)
VCC_5V_CAN: R29.2, TCAN1051HGVDR1.5 (VIO)
VCC_12V: C12.1, C14.1, C15.1, C18.1, D4.2 (A), D5.2 (A), D6.2 (A), IR2136STRPBF1.4 (VCC), L1.2, R6.2, U2.1 (IN), U2.3 (EN)
Vshunt_1+: Q1.3 (S), R9.2, R20.1
Vshunt_2+: Q3.3 (S), R12.2, R15.2, R23.1
Vshunt_3+: Q5.3 (S), R26.1

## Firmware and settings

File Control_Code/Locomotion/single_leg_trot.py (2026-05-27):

"""
single_leg_trot.py

Run a regular planar cycloidal foot trajectory relative to the leg's current
raw motor position.

This script does not define CAN IDs, motor signs, or homing angles. It imports
all hardware-specific data from leg_config.py and imports foot trajectory math
from trajectory_config.py.

Example:
    python single_leg_trot.py --leg front_right
"""

from __future__ import annotations

import argparse
import math
import signal
import time
from typing import Dict, Iterable, List

import berkeley_humanoid_lite_lowlevel.recoil as recoil
from loop_rate_limiters import RateLimiter  # type: ignore[import-not-found]

from leg_config import (
    FRONT_RIGHT,
    GEAR_RATIO,
    HIP,
    JOINT_ORDER,
    LEG_ORDER,
    NEUTRAL_X,
    NEUTRAL_Y,
    NEUTRAL_Z,
    get_can_channel,
    get_joint_gains,
    get_motor_sign,
    get_role_to_id_for_leg,
)
from trajectory_config import (
    JOINT_ROLES,
    ROLE_HIP,
    ROLE_SHANK,
    ROLE_THIGH,
    TRAJ_REGULAR_PLANAR,
    TrajectoryConfig,
    TrajectoryPoint,
    build_angle_delta_table,
    summarize_angle_delta_table,
)


TRAJECTORY_NAME = TRAJ_REGULAR_PLANAR
TRAJ_CFG = TrajectoryConfig(
    x_center=NEUTRAL_X,
    y_center=NEUTRAL_Y,
    z_ground=NEUTRAL_Z,
    step_length=100.0,
    step_height=70.0,
    step_sideways=0.0,
    stance_ratio=0.50,
    cycle_time=1.20,
    rate_hz=80.0,
    x_forward_sign=1.0,
    y_sideways_sign=1.0,
    z_lift_sign=-1.0,
    heading_deg=45.0,
    z_jump_amplitude=80.0,
)

COMMAND_HIP_TRAJECTORY = False
COMMAND_ROLES = JOINT_ROLES if COMMAND_HIP_TRAJECTORY else (ROLE_THIGH, ROLE_SHANK)
COMMAND_ORDER_ROLES = (ROLE_THIGH, ROLE_SHANK, ROLE_HIP)

RATE_HZ = TRAJ_CFG.rate_hz
PRINT_EVERY = 40
STARTUP_HOLD_TIME = 0.8
MOVE_TO_FIRST_TIME = 0.8

ARM_KP = 0.0
ARM_KD = 0.0
ARM_TORQUE_LIMIT = 0.0

STARTUP_KP = 0.003
STARTUP_KD = 0.001
STARTUP_TORQUE_LIMIT = 0.03

MAX_TRAJ_RAW_DELTA_BY_ROLE = {
    ROLE_HIP: 8.0,
    ROLE_THIGH: 13.0,
    ROLE_SHANK: 13.0,
}

STOP_REQUESTED = False


def request_stop(_signum=None, _frame=None) -> None:
    global STOP_REQUESTED
    STOP_REQUESTED = True
    print("\nStop requested.")


signal.signal(signal.SIGINT, request_stop)
signal.signal(signal.SIGTERM, request_stop)


def parse_args() -> argparse.Namespace:
    parser = argparse.ArgumentParser()
    parser.add_argument(
        "--leg",
        choices=LEG_ORDER,
        default=FRONT_RIGHT,
        help="Leg hardware config to use from leg_config.py.",
    )
    return parser.parse_args()


class SingleLegRunner:
    """Low-level helper for one configured physical leg."""

    def __init__(self, leg_name: str):
        self.leg_name = leg_name
        self.channel = get_can_channel(leg_name)
        self.role_to_id = get_role_to_id_for_leg(leg_name)
        self.id_to_role = {motor_id: role for role, motor_id in self.role_to_id.items()}
        self.motor_ids = [self.role_to_id[role] for role in JOINT_ORDER]
        self.command_order = [self.role_to_id[role] for role in COMMAND_ORDER_ROLES]
        self.bus = recoil.Bus(channel=self.channel, bitrate=1000000)
        self.rate = RateLimiter(frequency=RATE_HZ)
        self.active_cmd: Dict[int, float] = {}

    def set_mode_with_spacing(self, motor_id: int, mode) -> None:
        self.bus.set_mode(motor_id, mode)
        time.sleep(0.008)
        try:
            self.bus.feed(motor_id)
        except Exception:
            pass
        time.sleep(0.008)

    def set_gains(
        self,
        motor_id: int,
        kp: float,
        kd: float,
        torque_limit: float,
    ) -> None:
        self.bus.write_position_kp(motor_id, kp)
        time.sleep(0.004)
        self.bus.write_position_kd(motor_id, kd)
        time.sleep(0.004)
        self.bus.write_torque_limit(motor_id, torque_limit)
        time.sleep(0.004)

    def set_role_gains_from_config(self, role: str) -> None:
        motor_id = self.role_to_id[role]
        kp, kd, torque_limit = get_joint_gains(self.leg_name, role)
        self.set_gains(motor_id, kp, kd, torque_limit)

    def set_all_config_gains(self) -> None:
        for role in JOINT_ORDER:
            self.set_role_gains_from_config(role)

    def set_all_soft_startup_gains(self) -> None:
        for motor_id in self.motor_ids:
            self.set_gains(motor_id, STARTUP_KP, STARTUP_KD, STARTUP_TORQUE_LIMIT)

    def read_position(self, motor_id: int) -> float:
        value = self.bus.read_position_measured(motor_id)
        if value is None:
            raise RuntimeError(
                f"read_position_measured returned None for ID {motor_id}"
            )
        return float(value)

    def read_all_positions(self, samples: int = 15) -> Dict[int, float]:
        values_by_id: Dict[int, List[float]] = {
            motor_id: []
            for motor_id in self.motor_ids
        }

        for _ in range(samples):
            for motor_id in self.motor_ids:
                try:
                    values_by_id[motor_id].append(self.read_position(motor_id))
                except Exception as exc:
                    role = self.id_to_role[motor_id]
                    print(f"  Read warning for {role} ID {motor_id}: {exc}")
                time.sleep(0.003)
            self.rate.sleep()

        raw = {}
        for motor_id, values in values_by_id.items():
            if not values:
                raise RuntimeError(f"No valid samples for ID {motor_id}")
            values.sort()
            raw[motor_id] = values[len(values) // 2]
        return raw

    def command_position(self, motor_id: int, raw_target: float) -> None:
        self.bus.transmit_pdo_2(motor_id, raw_target, 0.0)
        self.active_cmd[motor_id] = raw_target

    def command_targets(self, targets_by_id: Dict[int, float]) -> None:
        for motor_id in self.command_order:
            if motor_id in targets_by_id:
                self.command_position(motor_id, targets_by_id[motor_id])

    def command_all_active(self) -> None:
        self.command_targets(self.active_cmd)

    def arm_at_current_pose(self) -> Dict[int, float]:
        print("\nPutting motors into IDLE before reading current pose...")
        for motor_id in self.motor_ids:
            self.set_mode_with_spacing(motor_id, recoil.Mode.IDLE)
        time.sleep(0.25)

        print("\nReading current raw positions...")
        start_raw = self.read_all_positions()
        for role in JOINT_ORDER:
            motor_id = self.role_to_id[role]
            print(f"  {role:5s} ID {motor_id}: raw={start_raw[motor_id]:+.6f}")

        print("\nArming POSITION mode at zero torque...")
        for motor_id in self.motor_ids:
            self.set_gains(motor_id, ARM_KP, ARM_KD, ARM_TORQUE_LIMIT)
            self.set_mode_with_spacing(motor_id, recoil.Mode.POSITION)

        self.active_cmd = dict(start_raw)
        for _ in range(int(0.35 * RATE_HZ)):
            self.command_all_active()
            self.rate.sleep()

        print("Applying soft startup gains...")
        self.set_all_soft_startup_gains()
        for _ in range(int(STARTUP_HOLD_TIME * RATE_HZ)):
            self.command_all_active()
            self.rate.sleep()

        return start_raw

    def raw_delta_for_role(self, role: str, angle_delta: float) -> float:
        return get_motor_sign(self.leg_name, role) * angle_delta * GEAR_RATIO

    def targets_from_reference(
        self,
        reference_raw: Dict[int, float],
        point: TrajectoryPoint,
        command_roles: Iterable[str] = COMMAND_ROLES,
    ) -> Dict[int, float]:
        targets = {}
        for role in command_roles:
            motor_id = self.role_to_id[role]
            raw_delta = self.raw_delta_for_role(role, point.angle_delta_by_role[role])
            targets[motor_id] = reference_raw[motor_id] + raw_delta

        if not COMMAND_HIP_TRAJECTORY:
            hip_id = self.role_to_id[HIP]
            targets[hip_id] = reference_raw[hip_id]

        return targets

    def move_to_targets(
        self,
        targets: Dict[int, float],
        move_time: float,
        label: str,
        print_every: int = 0,
    ) -> None:
        print(f"\n{label}")
        start_cmd = dict(self.active_cmd)
        steps = max(1, int(move_time * RATE_HZ))
        print(f"  sending interpolated targets for {steps} control steps")

        for i in range(steps):
            if STOP_REQUESTED:
                return

            u = (i + 1) / steps
            s = 0.5 * (1.0 - math.cos(math.pi * u))
            cmd = {
                motor_id: start_cmd[motor_id] + (target - start_cmd[motor_id]) * s
                for motor_id, target in targets.items()
            }
            self.command_targets(cmd)

            if print_every > 0 and (i + 1) % print_every == 0:
                self.print_feedback()

            self.rate.sleep()

    def print_feedback(self) -> None:
        try:
            measured = self.read_all_positions(samples=1)
        except Exception as exc:
            print(f"read warning: {exc}")
            return

        parts = []
        for motor_id in self.command_order:
            role = self.id_to_role[motor_id]
            cmd = self.active_cmd.get(motor_id, measured[motor_id])
            parts.append(f"{role}:err={cmd - measured[motor_id]:+.3f}")
        print(" | ".join(parts))

    def idle_all(self) -> None:
        print("\nPutting motors into IDLE...")
        for motor_id in self.motor_ids:
            try:
                self.set_mode_with_spacing(motor_id, recoil.Mode.IDLE)
                print(f"  {self.id_to_role[motor_id]} ID {motor_id} IDLE")
            except Exception as exc:
                print(f"  Failed to idle ID {motor_id}: {exc}")
        try:
            self.bus.stop()
        except Exception:
            pass

def print_trajectory_summary(
    runner: SingleLegRunner,
    table: List[TrajectoryPoint],
) -> None:
    summary = summarize_angle_delta_table(table)
    print("\nTrajectory table summary:")

    for role in JOINT_ROLES:
        max_angle = summary[role]["max_abs_angle_delta"]
        max_raw = max(
            abs(runner.raw_delta_for_role(role, point.angle_delta_by_role[role]))
            for point in table
        )
        limit = MAX_TRAJ_RAW_DELTA_BY_ROLE[role]
        print(
            f"  {role:5s}: max angle delta={max_angle:+.6f} rad, "
            f"max raw delta={max_raw:+.3f}, limit={limit:.3f}"
        )
        if max_raw > limit:
            raise RuntimeError(f"{role} trajectory raw delta exceeds safety limit.")


def main() -> None:
    args = parse_args()
    runner = SingleLegRunner(args.leg)

    try:
        print("=" * 80)
        print("single_leg_trot.py")
        print("=" * 80)
        print(f"leg={runner.leg_name}, channel={runner.channel}")
        print(f"trajectory={TRAJECTORY_NAME}, command_hip={COMMAND_HIP_TRAJECTORY}")
        print("role -> CAN ID:")
        for role in JOINT_ORDER:
            print(f"  {role:5s} -> ID {runner.role_to_id[role]}")
        print("=" * 80)

        start_raw = runner.arm_at_current_pose()

        table = build_angle_delta_table(TRAJECTORY_NAME, TRAJ_CFG)
        print_trajectory_summary(runner, table)

        first_targets = runner.targets_from_reference(start_raw, table[0])

        print("\nSwitching to leg_config.py run gains...")
        runner.set_all_config_gains()
        runner.move_to_targets(
            first_targets,
            MOVE_TO_FIRST_TIME,
            "Moving to first trajectory point...",
        )

        print("\nStarting regular planar trajectory. Press Ctrl+C to stop.\n")
        index = 0
        counter = 0

        while not STOP_REQUESTED:
            point = table[index]
            targets = runner.targets_from_reference(start_raw, point)
            runner.command_targets(targets)

            counter += 1
            if counter % PRINT_EVERY == 0:
                foot = point.foot
                deltas = point.angle_delta_by_role
                print(
                    f"phase={point.phase:.3f} {point.phase_name} | "
                    f"x={foot.x:+.1f} y={foot.y:+.1f} z={foot.z:+.1f} | "
                    f"dAng hip={deltas[ROLE_HIP]:+.4f} "
                    f"thigh={deltas[ROLE_THIGH]:+.4f} "
                    f"shank={deltas[ROLE_SHANK]:+.4f}"
                )
                runner.print_feedback()

            index = (index + 1) % len(table)
            runner.rate.sleep()

    except KeyboardInterrupt:
        request_stop()

    finally:
        runner.idle_all()


if __name__ == "__main__":
    main()

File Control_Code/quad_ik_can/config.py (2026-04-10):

# =============================================================================
#  QUAD LEG IK — CONFIGURATION
#  UCB Recoil FOC Firmware (STM32G431 B-G431B-ESC1)
#
#  Edit this file to match your hardware. All other files read from here.
# =============================================================================

import math

# -----------------------------------------------------------------------------
#  CAN BUS  (CANable via SocketCAN)
# -----------------------------------------------------------------------------
CAN_INTERFACE   = "socketcan"
CAN_CHANNEL     = "can0"        # run: sudo bash scripts/setup_can.sh
CAN_BITRATE     = 1_000_000     # must match FDCAN1 config in firmware
CAN_TIMEOUT     = 0.05

# -----------------------------------------------------------------------------
#  RECOIL FIRMWARE — CAN PROTOCOL
#
#  11-bit standard CAN ID layout:
#     bits [10:7]  = FUNC_ID   (4 bits, function code)
#     bits  [6:0]  = DEVICE_ID (7 bits, node address)
#
#  CAN ID = (FUNC_ID << 7) | DEVICE_ID
# -----------------------------------------------------------------------------
FUNC_NMT             = 0x00   # Network Management — set operating mode
FUNC_SYNC_EMCY       = 0x01   # Sync / emergency
FUNC_RECEIVE_SDO     = 0x02   # SDO read/write any parameter by byte offset
FUNC_RECEIVE_PDO_1   = 0x03   # PDO1 RX — echo test frame
FUNC_RECEIVE_PDO_2   = 0x04   # PDO2 RX — [position_target, velocity_target]
FUNC_RECEIVE_PDO_3   = 0x05   # PDO3 RX — [position_target, torque_feedfwd]
FUNC_RECEIVE_PDO_4   = 0x06   # PDO4 RX — fast-frame slot (TX-only from ESC)
FUNC_FLASH           = 0x07   # Flash store (0x01) / load (0x02)
FUNC_HEARTBEAT       = 0x08   # Resets watchdog timer on ESC

FUNC_TRANSMIT_PDO_1  = 0x09   # PDO1 TX — echo reply
FUNC_TRANSMIT_PDO_2  = 0x0A   # PDO2 TX — [position_measured, velocity_measured]
FUNC_TRANSMIT_PDO_3  = 0x0B   # PDO3 TX — [position_measured, torque_measured]
FUNC_TRANSMIT_PDO_4  = 0x0C   # PDO4 TX — fast-frame [position, velocity]
FUNC_TRANSMIT_SDO    = 0x0D   # SDO reply

# Operating mode bytes (sent in NMT frame data[0]) — must match firmware enum
MODE_DISABLED            = 0x00
MODE_CALIBRATION         = 0x01
MODE_IDLE                = 0x02
MODE_DAMPING             = 0x03
MODE_CURRENT             = 0x04
MODE_TORQUE              = 0x05
MODE_VELOCITY            = 0x06
MODE_POSITION            = 0x07   # ← used for IK leg control
MODE_VQD_OVERRIDE        = 0x08
MODE_VALPHABETA_OVERRIDE = 0x09
MODE_VABC_OVERRIDE       = 0x0A
MODE_DEBUG               = 0x0B

# -----------------------------------------------------------------------------
#  DEVICE IDs — one per joint
#  Each ESC must be flashed with a unique DEVICE_CAN_ID in firmware.
#  Check/set via SDO or by recompiling with DEVICE_CAN_ID defined.
# -----------------------------------------------------------------------------
DEVICE_ID_HIP   = 0x01   # hip   ESC CAN node
DEVICE_ID_KNEE  = 0x02   # knee  ESC CAN node
DEVICE_ID_ANKLE = 0x03   # ankle ESC CAN node

# -----------------------------------------------------------------------------
#  PDO SELECTION
#
#  PDO2 (recommended): send [position_target (rad), velocity_target (rad/s)]
#                      recv [position_measured (rad), velocity_measured (rad/s)]
#
#  PDO3:               send [position_target (rad), torque_feedforward (Nm)]
#                      recv [position_measured (rad), torque_measured (Nm)]
#
#  All values are IEEE-754 float32, little-endian, packed back-to-back.
#  DLC = 8 bytes for all PDO frames.
# -----------------------------------------------------------------------------
USE_PDO = 2                  # 2 or 3
VELOCITY_FEEDFORWARD = 0.0   # rad/s — sent in PDO2
TORQUE_FEEDFORWARD   = 0.0   # Nm    — sent in PDO3

# -----------------------------------------------------------------------------
#  LEG GEOMETRY  (mm)
#
#  Motor layout:
#    DEVICE_ID_HIP   -- SHOULDER tilt: swings leg laterally in/out
#    DEVICE_ID_KNEE  -- THIGH pitch:   swings thigh forward/back
#    DEVICE_ID_ANKLE -- SHIN via push-rod that runs through the thigh
#
#  L1 = thigh link  (shoulder/hip pivot -> knee pivot)
#  L2 = shin  link  (knee pivot -> foot contact point)
#  L3 = foot  stub  -- set 0 if no rigid foot extension
#
#  SHIN_IS_ABSOLUTE:
#    True  -- push-rod holds shin at an ABSOLUTE world-frame angle regardless
#             of thigh angle (typical parallelogram / push-rod behaviour).
#             Motor 3 command = shin angle from world +X axis.
#    False -- motor 3 command = shin angle RELATIVE to the thigh.
#  Start with True. Flip if the foot moves the wrong direction.
#
#  SHOULDER_TO_HIP_MM -- lateral distance between shoulder pivot and hip pivot.
# -----------------------------------------------------------------------------
L1 = 100.0   # mm -- thigh
L2 =  90.0   # mm -- shin
L3 =   0.0   # mm -- foot stub (0 = no foot link)

SHIN_IS_ABSOLUTE    = True
SHOULDER_TO_HIP_MM  = 0.0
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

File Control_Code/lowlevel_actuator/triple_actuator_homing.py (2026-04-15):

import time
import math

from loop_rate_limiters import RateLimiter
import berkeley_humanoid_lite_lowlevel.recoil as recoil


args = recoil.util.get_args()
bus = recoil.Bus(channel=args.channel, bitrate=1000000)

# -----------------------------
# Motor IDs
# -----------------------------
HIP_ID = 2
THIGH_ID = 1
SHANK_ID = 0

MOTOR_IDS = [HIP_ID, THIGH_ID, SHANK_ID]
MOTOR_NAMES = {
    HIP_ID: "Hip",
    THIGH_ID: "Thigh",
    SHANK_ID: "Shank",
}

# -----------------------------
# Final gains
# -----------------------------
kp = 0.2
kd = 0.005
torque_limit = 0.8

# -----------------------------
# Very soft startup gains
# -----------------------------
startup_kp = 0.003
startup_kd = 0.001
startup_torque_limit = 0.03

mid_kp = 0.03
mid_kd = 0.002
mid_torque_limit = 0.10

# -----------------------------
# Relative motion command
# positive = CCW, negative = CW
# Same delta for all 3 joints
# -----------------------------
delta_theta = 12.0

# -----------------------------
# Motion timing
# -----------------------------
move_duration = 2.0

rate_hz = 200.0
rate = RateLimiter(frequency=rate_hz)

# -----------------------------
# Startup stability settings
# -----------------------------
stable_velocity_threshold = 0.2
required_stable_samples = 30
max_startup_time = 4.0

print_every = 20

print("Entering damping mode for startup settle...")
for motor_id in MOTOR_IDS:
    bus.set_mode(motor_id, recoil.Mode.DAMPING)
    bus.feed(motor_id)
    time.sleep(0.003)

time.sleep(0.1)

# --------------------------------
# Wait for stable encoder readings in damping mode
# --------------------------------
stable_positions = {
    HIP_ID: [],
    THIGH_ID: [],
    SHANK_ID: [],
}
stable_count = 0

t_start = time.perf_counter()

while True:
    measured = {}
    valid = True
    all_stable = True

    for motor_id in MOTOR_IDS:
        measured_position, measured_velocity = bus.write_read_pdo_2(
            motor_id, 0.0, 0.0
        )
        measured[motor_id] = (measured_position, measured_velocity)

        if measured_position is None or measured_velocity is None:
            valid = False
        elif abs(measured_velocity) >= stable_velocity_threshold:
            all_stable = False

        time.sleep(0.001)

    if valid:
        if all_stable:
            for motor_id in MOTOR_IDS:
                stable_positions[motor_id].append(measured[motor_id][0])
            stable_count += 1
        else:
            for motor_id in MOTOR_IDS:
                stable_positions[motor_id].clear()
            stable_count = 0

        if stable_count >= required_stable_samples:
            break

    if (time.perf_counter() - t_start) > max_startup_time:
        for motor_id in MOTOR_IDS:
            bus.set_mode(motor_id, recoil.Mode.IDLE)
            time.sleep(0.003)
        bus.stop()
        raise RuntimeError(
            "Could not get stable encoder positions at startup."
        )

    rate.sleep()

start_positions = {}
target_positions = {}

for motor_id in MOTOR_IDS:
    start_positions[motor_id] = (
        sum(stable_positions[motor_id]) / len(stable_positions[motor_id])
    )
    target_positions[motor_id] = start_positions[motor_id] + delta_theta

print("Stable start positions:")
for motor_id in MOTOR_IDS:
    print(
        f"{MOTOR_NAMES[motor_id]}: "
        f"start={start_positions[motor_id]:.3f} rad | "
        f"target={target_positions[motor_id]:.3f} rad"
    )

# --------------------------------
# Enter position mode very softly
# --------------------------------
for motor_id in MOTOR_IDS:
    bus.write_position_kp(motor_id, startup_kp)
    bus.write_position_kd(motor_id, startup_kd)
    bus.write_torque_limit(motor_id, startup_torque_limit)
    time.sleep(0.003)

for motor_id in MOTOR_IDS:
    bus.set_mode(motor_id, recoil.Mode.POSITION)
    bus.feed(motor_id)
    time.sleep(0.003)

time.sleep(0.05)

# Hold current positions softly first
print("Soft hold...")
hold_time_1 = 0.6
hold_steps_1 = int(hold_time_1 * rate_hz)

for _ in range(hold_steps_1):
    for motor_id in MOTOR_IDS:
        bus.write_read_pdo_2(
            motor_id,
            start_positions[motor_id],
            0.0,
        )
        time.sleep(0.001)
    rate.sleep()

# --------------------------------
# Ramp to medium gains
# --------------------------------
for motor_id in MOTOR_IDS:
    bus.write_position_kp(motor_id, mid_kp)
    bus.write_position_kd(motor_id, mid_kd)
    bus.write_torque_limit(motor_id, mid_torque_limit)
    time.sleep(0.003)

hold_time_2 = 0.5
hold_steps_2 = int(hold_time_2 * rate_hz)

for _ in range(hold_steps_2):
    for motor_id in MOTOR_IDS:
        bus.write_read_pdo_2(
            motor_id,
            start_positions[motor_id],
            0.0,
        )
        time.sleep(0.001)
    rate.sleep()

# --------------------------------
# Switch to final gains
# --------------------------------
for motor_id in MOTOR_IDS:
    bus.write_position_kp(motor_id, kp)
    bus.write_position_kd(motor_id, kd)
    bus.write_torque_limit(motor_id, torque_limit)
    time.sleep(0.003)

# --------------------------------
# Smooth cosine move
# q(t) = q0 + dq/2 * (1 - cos(pi*t/T))
# zero start/end velocity
# --------------------------------
print("Starting smooth move...")
t0 = time.perf_counter()
counter = 0

try:
    while True:
        t = time.perf_counter() - t0

        if t >= move_duration:
            s = 1.0
        else:
            s = 0.5 * (1.0 - math.cos(math.pi * t / move_duration))

        measured = {}

        for motor_id in MOTOR_IDS:
            command_angle = start_positions[motor_id] + delta_theta * s

            measured_position, measured_velocity = bus.write_read_pdo_2(
                motor_id,
                command_angle,
                0.0,
            )

            measured[motor_id] = (command_angle, measured_position, measured_velocity)
            time.sleep(0.001)

        counter += 1
        if counter % print_every == 0:
            for motor_id in MOTOR_IDS:
                command_angle, measured_position, measured_velocity = measured[motor_id]
                if measured_position is not None and measured_velocity is not None:
                    print(
                        f"{MOTOR_NAMES[motor_id]} | "
                        f"Cmd: {command_angle:.3f} | "
                        f"Target: {target_positions[motor_id]:.3f} | "
                        f"Measured pos: {measured_position:.3f} | "
                        f"vel: {measured_velocity:.3f}"
                    )
            print("-----")

        rate.sleep()

except KeyboardInterrupt:
    pass

for motor_id in MOTOR_IDS:
    bus.set_mode(motor_id, recoil.Mode.IDLE)
    time.sleep(0.003)

bus.stop()

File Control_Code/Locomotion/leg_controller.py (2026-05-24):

"""
leg_controller.py

One reusable controller for one physical leg.

Hardware details come from leg_config.py. Trajectory points are pure
output-side angle deltas from trajectory_config.py. This class is the place
where those angle deltas become raw motor targets.
"""

from __future__ import annotations

import time
from typing import Dict, Iterable, Optional

import berkeley_humanoid_lite_lowlevel.recoil as recoil

from gains_config import ARM_GAINS, HOLD_GAINS, GainSet
from leg_config import (
    GEAR_RATIO,
    HIP,
    JOINT_ORDER,
    SHANK,
    THIGH,
    get_can_channel,
    get_max_contraction_angles_for_leg,
    get_motor_sign,
    get_role_to_id_for_leg,
)
from trajectory_config import JOINT_ROLES, TrajectoryPoint, ik_angles_for_xyz


COMMAND_ORDER_ROLES = (THIGH, SHANK, HIP)


class LegController:
    """Controller for one configured physical leg."""

    def __init__(self, name: str, rate_hz: float):
        self.name = name
        self.rate_hz = rate_hz
        self.channel = get_can_channel(name)

        self.role_to_id = get_role_to_id_for_leg(name)
        self.id_to_role = {
            motor_id: role
            for role, motor_id in self.role_to_id.items()
        }

        self.hip_id = self.role_to_id[HIP]
        self.thigh_id = self.role_to_id[THIGH]
        self.shank_id = self.role_to_id[SHANK]

        self.motor_ids = [self.role_to_id[role] for role in JOINT_ORDER]
        self.command_order = [
            self.role_to_id[role]
            for role in COMMAND_ORDER_ROLES
        ]

        self.bus = recoil.Bus(channel=self.channel, bitrate=1000000)

        self.limit_raw: Optional[Dict[int, float]] = None
        self.neutral_raw: Optional[Dict[int, float]] = None
        self.active_cmd: Dict[int, float] = {}
        self.state = "unhomed"

    # ========================================================
    # Low-level API
    # ========================================================

    def set_mode_with_spacing(self, motor_id: int, mode) -> None:
        self.bus.set_mode(motor_id, mode)
        time.sleep(0.006)
        try:
            self.bus.feed(motor_id)
        except Exception:
            pass
        time.sleep(0.006)

    def set_gains(
        self,
        motor_id: int,
        kp: float,
        kd: float,
        torque_limit: float,
    ) -> None:
        self.bus.write_position_kp(motor_id, kp)
        time.sleep(0.003)
        self.bus.write_position_kd(motor_id, kd)
        time.sleep(0.003)
        self.bus.write_torque_limit(motor_id, torque_limit)
        time.sleep(0.003)

    def set_role_gains(self, motor_id: int, gains: GainSet) -> None:
        role = self.id_to_role[motor_id]
        self.set_gains(
            motor_id,
            gains.kp[role],
            gains.kd[role],
            gains.torque[role],
        )

    def set_all_gains(self, gains: GainSet) -> None:
        for motor_id in self.motor_ids:
            self.set_role_gains(motor_id, gains)

    def read_position(self, motor_id: int) -> float:
        value = self.bus.read_position_measured(motor_id)
        if value is None:
            raise RuntimeError(
                f"{self.name}: read_position_measured None "
                f"for ID {motor_id}"
            )
        return float(value)

    def read_all_positions(self) -> Dict[int, float]:
        values = {}
        for motor_id in self.motor_ids:
            values[motor_id] = self.read_position(motor_id)
            time.sleep(0.003)
        return values

    def command_position(self, motor_id: int, raw_target: float) -> None:
        self.bus.transmit_pdo_2(motor_id, raw_target, 0.0)
        self.active_cmd[motor_id] = raw_target

    def command_targets(self, targets_by_id: Dict[int, float]) -> None:
        for motor_id in self.command_order:
            if motor_id in targets_by_id:
                self.command_position(motor_id, targets_by_id[motor_id])

    def command_all_active(self) -> None:
        self.command_targets(self.active_cmd)

    def idle(self) -> None:
        print(f"\n{self.name}: IDLE")
        for motor_id in self.motor_ids:
            try:
                self.set_mode_with_spacing(motor_id, recoil.Mode.IDLE)
                role = self.id_to_role[motor_id]
                print(f"  {self.name} {role} ID {motor_id} IDLE")
            except Exception as exc:
                print(f"  {self.name}: failed to idle ID {motor_id}: {exc}")

    def stop_bus(self) -> None:
        try:
            self.bus.stop()
        except Exception:
            pass

    # ========================================================
    # Conversion helpers
    # ========================================================

    def raw_delta_for_role(self, role: str, angle_delta: float) -> float:
        """Convert output-side joint angle delta into raw motor delta."""
        return get_motor_sign(self.name, role) * angle_delta * GEAR_RATIO

    def raw_targets_from_angle_deltas(
        self,
        reference_raw: Dict[int, float],
        angle_delta_by_role: Dict[str, float],
        command_roles: Iterable[str] = JOINT_ROLES,
    ) -> Dict[int, float]:
        targets = {}
        for role in command_roles:
            motor_id = self.role_to_id[role]
            raw_delta = self.raw_delta_for_role(
                role,
                angle_delta_by_role[role],
            )
            targets[motor_id] = reference_raw[motor_id] + raw_delta
        return targets

    # ========================================================
    # Homing / neutral
    # ========================================================

    def mark_homed_at_current_pose(self) -> None:
        """Record current raw position as this leg's max-contraction pose."""
        print()
        print(f"{self.name}: marking homed at current max-contraction pose...")

        raw = self.read_all_positions()
        self.limit_raw = raw
        self.active_cmd = dict(raw)

        for role in JOINT_ORDER:
            motor_id = self.role_to_id[role]
            print(
                f"  {self.name} {role:5s} ID {motor_id}: "
                f"raw={raw[motor_id]:+.6f}"
            )

        self.set_all_gains(ARM_GAINS)
        for motor_id in self.motor_ids:
            self.set_mode_with_spacing(motor_id, recoil.Mode.POSITION)

        for _ in range(int(0.25 * self.rate_hz)):
            self.command_all_active()
            time.sleep(1.0 / self.rate_hz)

        self.set_all_gains(HOLD_GAINS)
        for _ in range(int(0.25 * self.rate_hz)):
            self.command_all_active()
            time.sleep(1.0 / self.rate_hz)

        self.state = "homed"
        print(f"{self.name}: homed and holding max-contraction pose.")
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

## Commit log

2026-01-09 Add files via upload
    First version schematic without footprint assignment, as a direct copy of BHL drive S1.
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2026-01-21 Cleaning up a bunch or ERC errors.
    There are 23 errors left. Some of them are because of pins that don't have any connections.
    [BHL S1 copied.kicad_pcb, BHL S1 copied.kicad_sch]
2026-01-21 Add files via upload
    I add the temperature sensing , fixed all the footprint errors for PCB layout, and did a edge cut on pcb to show out the physical dimension constraint
2026-01-21 Cleanup, Organization, and some edits
    Editing the schematic and the PCB. Fixed a lot of ERC errors. Organized the mess that it originally was.
    [BHL S1 copied.kicad_pcb, BHL S1 copied.kicad_sch]
2026-01-22 Organization along with more edits to schematic
    [BHL S1 copied.kicad_sch, STM32G431CBU6.step]
2026-01-22 saved pcb
    [BHL S1 copied.kicad_pcb]
2026-01-22 Final revision before PCB layout
    Footprint and most warnings fixed, smaller electrolytic capacitor
    [BHL S1 copied.kicad_pcb, BHL S1 copied.kicad_sch]
2026-01-22 Organized the file structure
    [BHL S1 copied.kicad_pcb, BHL S1 copied.kicad_sch, STM32G431CBU6.step]
2026-01-22 Fixed some errors
    [BHL S1 copied.kicad_sch]
2026-01-22 Changes to Schematic
    [BHL S1 copied.kicad_sch]
2026-01-22 Minor Changes to schematic
    [BHL S1 copied.kicad_sch]
2026-01-22 Error and Warning reduced, footprint updated
    [BHL S1 copied.kicad_pcb, BHL S1 copied.kicad_sch]
2026-01-22 imported 3d model and started work on pcb.
    Made pcb 4 layers. moved some components onto the board. Need to revisit the component selection for the electrolytic capacitors.
    [BHL S1 copied.kicad_pcb]
2026-01-23 changed a couple components
    worked on fixing net labels
2026-01-23 unlocked files
    [BHL S1 copied.kicad_pcb, BHL S1 copied.kicad_sch]
2026-01-23 Fixed GND Net label issue on PCB creation
    [BHL S1 copied.kicad_pcb, BHL S1 copied.kicad_sch]
2026-01-26 Terminator block added, footprint error fixed, 9 schematic errors remains, may need to update all file paths of the symbol library.
    Moo
    [BHL S1 copied.kicad_pcb, BHL S1 copied.kicad_sch]
2026-01-26 Pin header duplicated fixed
    [BHL S1 copied.kicad_pcb]
2026-01-26 Resonator footprint updated
    [BHL S1 copied.kicad_pcb, BHL S1 copied.kicad_sch]
2026-01-26 All extra 3d model uploaded
    [0530CDMCCDS-6R8MC_Inductor.stp, 3314J-1-103G_Trimerpot_Forthermal.stp, 39-30-1042_Terminal.stp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]
2026-01-27 Worked on the PCB layout
    [BHL S1 copied.kicad_pcb, BHL S1 copied.kicad_sch]
2026-01-27 update PCB
    [BHL S1 copied.kicad_pcb]
2026-01-27 Footprint and 3d model updated, PCB updated
    [BHL S1 copied.kicad_pcb, BHL S1 copied.kicad_sch, FD6288Q_GateDRIVER.stp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]
2026-01-28 Attempted to fix some errors
    [BHL S1 copied.kicad_sch]
2026-01-28 Fixed all Errors in Schematic and Started routing PCB traces
    [BHL S1 copied.kicad_pcb, BHL S1 copied.kicad_sch]
2026-01-29 PCB layout changes
    [BHL S1 copied.kicad_pcb]
2026-01-30 worked on PCB routing
    [BHL S1 copied.kicad_pcb, BHL S1 copied.kicad_sch]
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2026-01-31 Routed half the gate driver
    [BHL S1 copied.kicad_pcb, BHL S1 copied.kicad_sch]
2026-01-31 Finished Routing the Gate Driver!
    [BHL S1 copied.kicad_pcb, BHL S1 copied.kicad_sch]
2026-02-01 Can Bus Routed In PCB
    [BHL S1 copied.kicad_pcb, BHL S1 copied.kicad_sch, SW_PTS636_CNK.step]
2026-02-01 Finished Buck Converter, Switch, and Temp Resistor Routing
    [BHL S1 copied.kicad_pcb]
2026-02-02 Finished Routing the Magnetic Encoder and part of the STM32
    [BHL S1 copied.kicad_pcb]
2026-02-02 Finished the Board!!
    [BHL S1 copied.kicad_pcb, BHL S1 copied.kicad_sch]
2026-02-03 Finished PCB. Enlargened diameter to 70mm.
    [BHL S1 copied.kicad_pcb]
2026-02-04 Final Revision of PCB
    [BHL S1 Bill Of Materials.csv, BHL S1 copied.kicad_pcb]
2026-02-05 Finished Revision
    [BHL S1 copied.kicad_pcb, BHL S1 copied.kicad_sch]
2026-02-05 Position adjusted slightly
    [BHL S1 copied.kicad_pcb]
2026-02-05 screw hole fixed
    [BHL S1 copied.kicad_pcb]
2026-02-06 Fixed some traces.
    This is the final revision before sending to manufacture
    [BHL S1 copied-B_Cu.gbl, BHL S1 copied-B_Mask.gbs, BHL S1 copied-B_Paste.gbp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]
2026-02-06 Downloaded Gerber and removed lock
    [BHL S1 copied-B_Cu.gbl, BHL S1 copied-B_Mask.gbs, BHL S1 copied-B_Paste.gbp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]
2026-02-07 just had to access a couple files and created a numbers file for tracking component buying.
    [BHL S1 copied.csv]
2026-02-11 Purchasing files
    [BOM LIST FOC Drive Board.xlsx, Quadraped Robot Expense Tracker.xlsx]
2026-02-16 Major changes to BOM and Some organization to file structure
    [Ultimate BOM.xlsx]
2026-02-16 Finished the BOM
    [Ultimate BOM.xlsx]
2026-02-25 Documentation and KiCad Files changes
    [BHL S1 copied.kicad_pcb, BOM LIST FOC Drive Board.xlsx, Ultimate BOM.xlsx]
2026-02-26 Made some fixes to the PCB
    Fixed Diode, trace sizes, and placements
    [BHL S1 copied.kicad_pcb, BHL S1 copied.kicad_sch, STPS1L40M.step]
2026-02-26 Fixed Some footprint issues
    [BHL S1 copied.kicad_pcb]
2026-03-08 Fixed some PCB errors
    [BHL S1 copied.kicad_pcb]
2026-03-11 Removed lock from Kicad Files
    [Ultimate BOM.xlsx]
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2026-04-09 Control Codes big updates
    REL pos.py fixed with refreshing real time state position into reference position.
    Dual actuator become 3 actuator
    Foot Trajectory fixed with added gear ratio
    [run_foot_trajectory.py]
2026-04-10 updates to KICAD files
    [BHL S1 copied.kicad_pcb]
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2026-04-21 All link changed to Amazon link
    all link changed to Amazon link and some minor part quantity changes
    [Ultimate BOM.xlsx]
2026-04-21 updated BOM
    [Ultimate BOM.xlsx]
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2026-04-30 All 3D model of cycloidal gear box are uploaded
    [AS5600 Encoder Mount.STL, Actuator back cover for BG431.STL, Bearing Pressing for 10 by 22mm.STL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]
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2026-05-02 STL of body
    [Center Body.STL, Hip Body Frame Mount.STL, Hip Dual Support Face Panel.STL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]
2026-05-02 New folder for STL
    [Center Body.STL, Hip Body Frame Mount.STL, Hip Dual Support Face Panel.STL]
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2026-05-07 All body part stl uploaded
    [Center Body Flip Cover Mirrored.STL, Center Body Flip Cover.STL, Center Body Mirrored.STL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]
2026-05-08 3D model updated
    [Center Body Mirrored.STL, Center Body.STL, Hip Body Frame Mount.STL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]
2026-05-09 Create IMU Mount.STL
    [IMU Mount.STL]
2026-05-11 File clean up and locomotion updated
    [hip_thigh_coupling_log_20260430_010138.csv, hip_thigh_uncompensated_coupling_log_20260430_110528.csv, hip_thigh_uncompensated_coupling_log_20260430_112134.csv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]
2026-05-11 moo cow body uploaded
    [Center Body Mirrored.STL, Center Body.STL, Hip Body Frame Mount.STL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]
2026-05-14 leg component tolerance change
    [Quadruped Leg linkage.STL, Quadruped Small Leg whole.STL, Quadruped Thigh inner.STL]
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2026-05-18 Wall thickness changed
    [Center Body Mirrored.STL, Center Body.STL, Quadruped Thigh Mirrored Inner Right.STL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]
2026-05-18 Accessories updated
    [Center Body Flip Cover Mirrored.STL, Center Body Flip Cover.STL, Hip Axial Cover.STL]
2026-05-24 Control Code Updated, Cleaned up BY Codex
    [hip_thigh_coupling_log_20260430_010138.csv, hip_thigh_uncompensated_coupling_log_20260430_110528.csv, hip_thigh_uncompensated_coupling_log_20260430_112134.csv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]
2026-05-26 New bracket mechanical limit fixed
    [Quadruped Hip Bracket Left Front.STL, Quadruped Hip Bracket Left Rear.STL, Quadruped Hip Bracket Right Front.STL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]
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2026-05-29 Update Hip Dual Support Face Panel.STL
    [Hip Dual Support Face Panel.STL]
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
